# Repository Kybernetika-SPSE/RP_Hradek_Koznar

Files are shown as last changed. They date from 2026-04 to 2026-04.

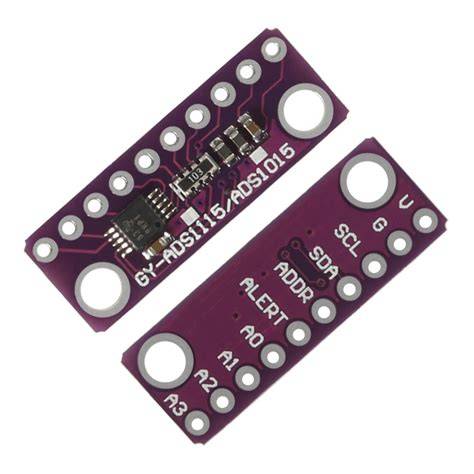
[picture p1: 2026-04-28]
RP_Hradek/reseni/AD_prevodnik/PRILOHA_XII_ads1115.jpg

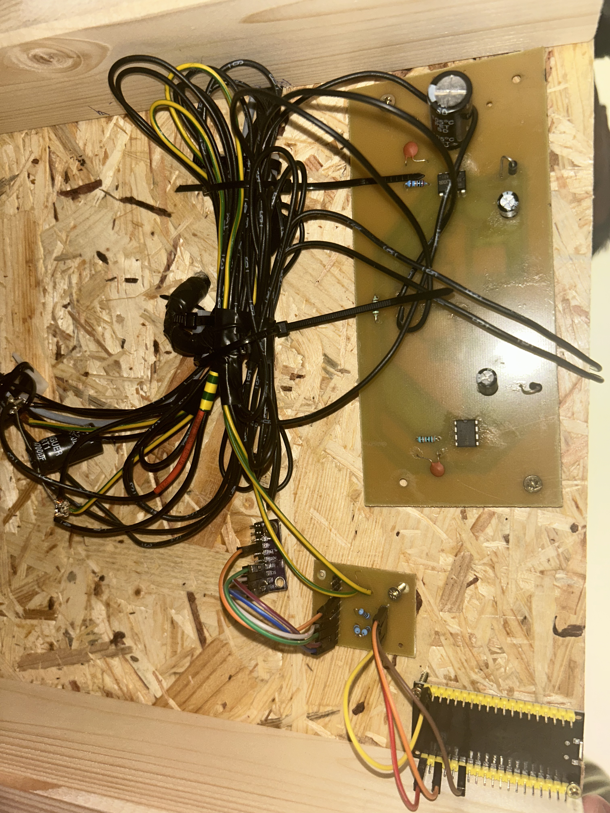
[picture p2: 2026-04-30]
RP_Hradek/reseni/real_fotky/hotovo.jpg

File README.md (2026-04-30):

# KYB Model větrné elektrárny

## Zadání projektu
Model větrné elektrárny

## Řešitelský tým
Štěpán Kožnar, Josef Hrádek

## Vedoucí
Jiří Švihla

## Oponent
Ing. Pavel Jedlička

## Shrnutí projektu
Funkční edukativní model vyrobený z HT potrubí a 3D tištěných PET dílů. Model simuluje přenos energie pomocí systému dvou motorů (motor-generátor) v uzavřené "strojní kleci". Dále zprostředkovává měrění výstupu a popisuje další změny při zpracovávání elektrické energie.

https://discord.gg/VVhzTzu8

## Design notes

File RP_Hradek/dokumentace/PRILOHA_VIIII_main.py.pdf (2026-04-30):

from machine import Pin, I2C
import time

i2c = I2C(0, scl=Pin(22), sda=Pin(21)) addr = 0x48

# kalibrace

gain = 1.00
offset = 0.08

# korekce nad 6V

korekce = 0.98

def read_adc_A0():
config = bytearray(2)
config[0] = 0xC2
config[1] = 0x83

i2c.writeto_mem(addr, 0x01, config) time.sleep(0.1)

data = i2c.readfrom_mem(addr, 0x00, 2)

raw = (data[0] << 8) | data[1]

if raw > 0x7FFF:
raw -= 0x10000

return raw

while True:
raw = read_adc_A0()

# napětí na vstupu ADS1115

v_adc = raw * 0.000125

# základní kalibrace

v_in = (v_adc * 4) * gain - offset

# rozdělení rozsahu

if v_in > 6:
v_in = v_in * korekce

# ochrana

if v_in < 0:
v_in = 0

print(round(v_in, 2))

time.sleep(0.5)

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
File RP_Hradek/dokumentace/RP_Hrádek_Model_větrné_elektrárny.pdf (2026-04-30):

## Vyšší odborná škola

## a Střední průmyslová škola elektrotechnická

## Plzeň, Koterovská 85

## ROCNˇ ÍKOVA PR ´ ACE ´

### Téma:

MODEL VETRN ˇ | E ELEKTR ´ | ARNY ´
Autor práce: | Josef Hrádek
Třída: | 3.L

## Vedoucí práce: Jiří Svihla ˇ

Dne: | 30. 4. 2026

## Hodnocení:

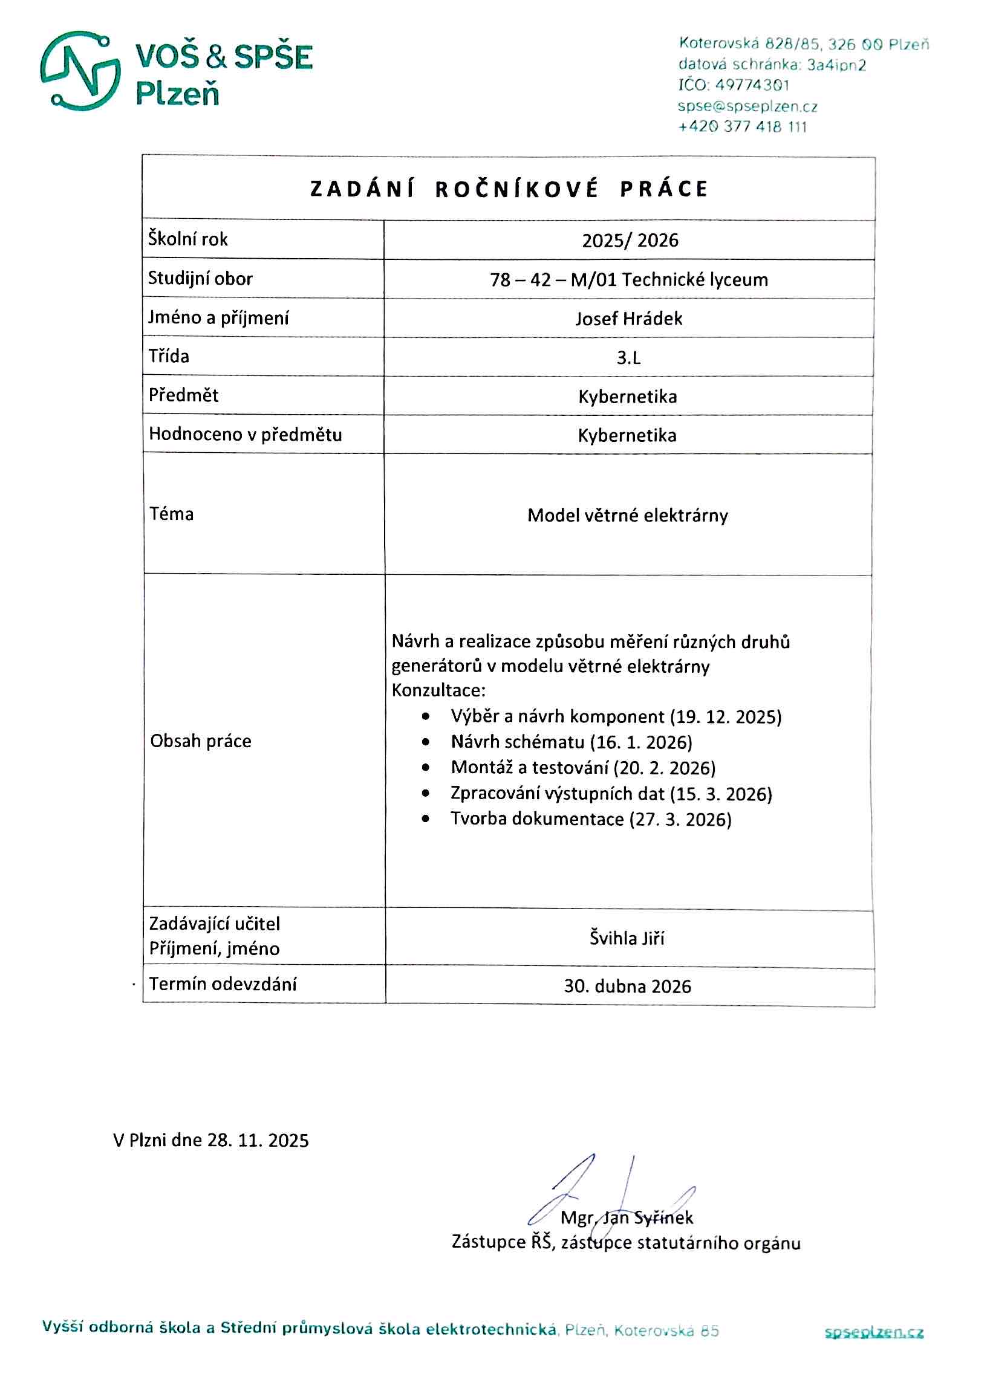
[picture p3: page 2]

## Anotace

Tato ročníková práce se zabývá návrhem a realizací modelu větrné elektrárny. Cílem

práce bylo vytvořit systém umožňující demonstraci přeměny mechanické energie na energii

elektrickou a její následné měření a zpracování.

### Abstrakt

This term project deals with the design and implementation of a model of a wind power

plant. The aim of the project was to create a system that enables the demonstration

of the conversion of mechanical energy into electrical energy, as well as its subsequent

measurement and processing

### Keywords

ADC, energy conversion, ESP32, generator, voltage measurement, wind power plant

Prohlašuji, že jsem tuto práci vypracoval samostatně a použil literárních pramenů a informací,

které cituji a uvádím v seznamu použité literatury a zdrojů informací.

Prohlašuji, že jsem nástroje UI využil v souladu s principy akademické integrity a že na

využití těchto nástrojů v práci vhodným způsobem odkazuji.

Souhlasím s využitím mé práce učiteli VOS a SP ˇ | SE Plzeň k výuce. ˇ
V Plzni dne 30. 4. 2026 | Podpis: |

## Poděkování

Tímto bych rád poděkoval vedoucímu práce Jiřímu Svihlovi za odborné vedení, pomoc ˇ

a připomínky při zpracování této práce. Poděkování patří také mé rodině za podporu

během zpracování této práce.

## Obsah

Seznam zkratek | 7
Uvod ´ | 8
1 Teoretický rozbor | 9
2 Návrh systému | 13

5

3 Praktická realizace | 22
4 Možné varianty řešení | 25
Závěr | 26
Literatura | 27
Přílohy | I

## Seznam zkratek

ADC | Analogově-digitální převodník
AC | Střídavé napětí
DC | Stejnosměrné napětí
ESP32 | Mikrokontrolér

I

2C | Sériová komunikační sběrnice

MOSFET Polem řízený tranzistor

PCB | Deska plošných spojů

7

## Uvod ´

Tato ročníková práce se zabývá návrhem a realizací modelu větrné elektrárny, který slouží

k demonstraci přeměny energie.

Cílem je vytvoření systému, který umožňuje znázornit přeměnu mechanické energie na

energii elektrickou a její následné zpracování. Model zároveň umožňuje měření napětí a

jeho další zpracování pomocí mikrokontroléru a počítače.

V rámci práce je řešen návrh elektrické části systému a měření napětí pomocí analogově-

digitálního převodníku a mikrokontroléru.

Součástí projektu je také popis celkového zapojení, jednotlivých komponent a jejich funkce

v systému.

Projekt byl realizován ve dvoučlenném týmu, přičemž každý člen byl zodpovědný za jinou

část práce. Tato práce se zaměřuje především na elektrickou část, zatímco mechanická

konstrukce modelu byla řešena druhým členem týmu.

Výsledkem práce je model větrné elektrárny s měřicím systémem, který umožňuje sle-

dování napětí a může sloužit jako názorná pomůcka při výuce.

8

## 1 Teoretický rozbor

### 1.1 Princip větrné elektrárny

Větrná elektrárna je zařízení, které přeměňuje kinetickou energii větru na energii elektric-

kou. Základem celého systému je rotor s lopatkami, který je roztáčen větrem.

Tato mechanická energie je následně přenášena na generátor, který ji přeměňuje na energii

elektrickou. Princip této přeměny je založen na elektromagnetické indukci, kdy pohyb

magnetického pole vůči vodiči způsobuje vznik elektrického napětí.

Velikost vyrobené elektrické energie závisí na několika faktorech. Mezi ty hlavní patří rych-

lost větru, velikost rotoru a účinnost jednotlivých částí systému. Se zvyšující se rychlostí

větru roste i výkon elektrárny.

Výkon větrné elektrárny lze přibližně vyjádřit vztahem 1.1:

P =

1
2

ρAv³
(1.1)

kde P je výkon větru, ρ hustota vzduchu, A plocha rotoru a v rychlost větru.

Princip větrné elektrárny je v rámci tohoto projektu využit v modelové podobě, která

umožňuje demonstraci přeměny energie a následné měření napětí.

### 1.2 Typy generátorů

Generátor je zařízení, které přeměňuje mechanickou energii na energii elektrickou. Ve

větrných elektrárnách je generátor poháněn rotorem a představuje tak klíčovou část z

hlediska výroby elektrické energie.

9

Z elektrického hlediska lze generátory rozdělit na stejnosměrné a střídavé podle charakteru

výstupního napětí.

### 1.2.1 Stejnosměrné generátory

Stejnosměrný generátor vytváří na výstupu napětí s konstantní polaritou. V jednodušších

aplikacích může být jako generátor použit například stejnosměrný motor provozovaný v

režimu generátoru, označovaný jako dynamo.

Výhodou tohoto řešení je především jednoduchost zapojení a snadné měření výstupního

napětí, protože není nutné dále upravovat signál před jeho zpracováním.

Základní vztah mezi elektrickými veličinami lze vyjádřit vztahem 1.2:

P = U · I | (1.2)

kde P je elektrický výkon, U napětí a I proud.

### 1.2.2 Střídavé generátory

Na rozdíl od stejnosměrných generátorů, střídavý generátor produkuje napětí, které se v

čase mění. Tento typ generátoru je běžný zejména u větších elektráren, kde je výhodný

pro přenos elektrické energie.

Pro další zpracování je však často nutné toto napětí upravit, například pomocí usměrňovače

nebo filtračních obvodů. Měření střídavého napětí je obecně složitější než u stejnosměrného

napětí, protože je nutné zohlednit jeho časový průběh nebo efektivní hodnotu.

Při výpočtu výkonu ve střídavých obvodech je nutné uvažovat také účiník, který vyjadřuje

fázový posun mezi napětím a proudem. Výkon lze pak vyjádřit vztahem 1.3:

10

P = U · I · cos φ | (1.3)

kde U je efektivní hodnota napětí, I efektivní hodnota proudu a cos φ účiník. Učiník ´

vyjadřuje poměr mezi skutečně využitým výkonem a celkovým zdánlivým výkonem ve střídavém obvodu. Učiník může nabývat hodnot mezi 0 a 1. Vyjadřuje fázový posun mezi ´

napětím a proudem.

V rámci tohoto projektu je proto využit stejnosměrný generátor, který umožňuje jed-

nodušší měření a zpracování získaných dat.

### 1.3 Přeměny elektrické energie

V elektrických systémech je často nutné upravovat vlastnosti elektrické energie podle

různých požadavků. Mezi základní úpravy patří změna typu napětí, jeho velikosti nebo

jeho časového průběhu.

Jednou ze základních přeměn je usměrnění, tedy převod střídavého napětí na napětí stej-

nosměrné. K tomu se používají usměrňovače, které jsou tvořeny nejčastěji polovodičovými

diodami a vyhlazovacím kondenzátorem.

Další důležitou přeměnou je převod stejnosměrného napětí na střídavé. Tento proces zajišt’ují střídače, které vytvářejí střídavé napětí z napětí stejnosměrného. Střídače se

využívají například u zařízení vyžadujících střídavé napětí nebo při připojení zdrojů ener-

gie k elektrické síti.

Pro změnu velikosti střídavého napětí se používají transformátory. Ty umožňují zvyšovat

nebo snižovat napětí podle potřeby. Proud je přitom nepřímo úměrný k napětí. Základní

vztah transformátoru lze vyjádřit vztahem 1.4:

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
(1.4)

kde U1 a U2 jsou napětí na primární a sekundární straně, I1 a I2 proudy na primární a

11 sekundární straně a N1, N2 počty závitů vinutí.

Učinnost přeměny lze vyjádřit jako poměr výstupního a vstupního výkonu podle vztahu 1.5: ´

η =

Pout

Pin

(1.5)

kde η je účinnost, Pout výstupní výkon a Pin vstupní výkon.

Každá z těchto přeměn je však spojena s energetickými ztrátami, které vznikají například

na polovodičových prvcích nebo vinutí transformátorů. Tyto ztráty se projevují snížením

účinnosti celého systému.

12

## 2 Návrh systému

Kapitola návrh systému se zaměřuje na návrh modelu větrné elektrárny z hlediska jeho

elektrické části. Zde jsem popsal jednotlivé bloky systému, jejich funkce a vzájemné pro-

pojení.

Veškeré obvody a PCB jsou navrženy v programu KiCad.

### 2.1 Blokové schéma systému

Navržený model větrné elektrárny mohu přehledně popsat pomocí blokového schématu,

které znázorňuje jednotlivé části systému a jejich vzájemné propojení. Blokové schéma

slouží jako základní orientační prvek pro pochopení funkce celého zařízení.

Na obrázku 2.1 je zobrazeno rozdělení systému do několika hlavních bloků. Prvním z nich

je generátor. Na generátor navazuje měřicí část, která umožňuje sledování napětí.

Další částí je zpracování elektrické energie vedené do energetické části, kde může docházet

k její další úpravě, například převodu na střídavé napětí a transformaci.

V blokovém schématu je vidět, že části systému jsou navrženy modulárně, takže je možné

abych je jednoduše a samostatně testoval.

13

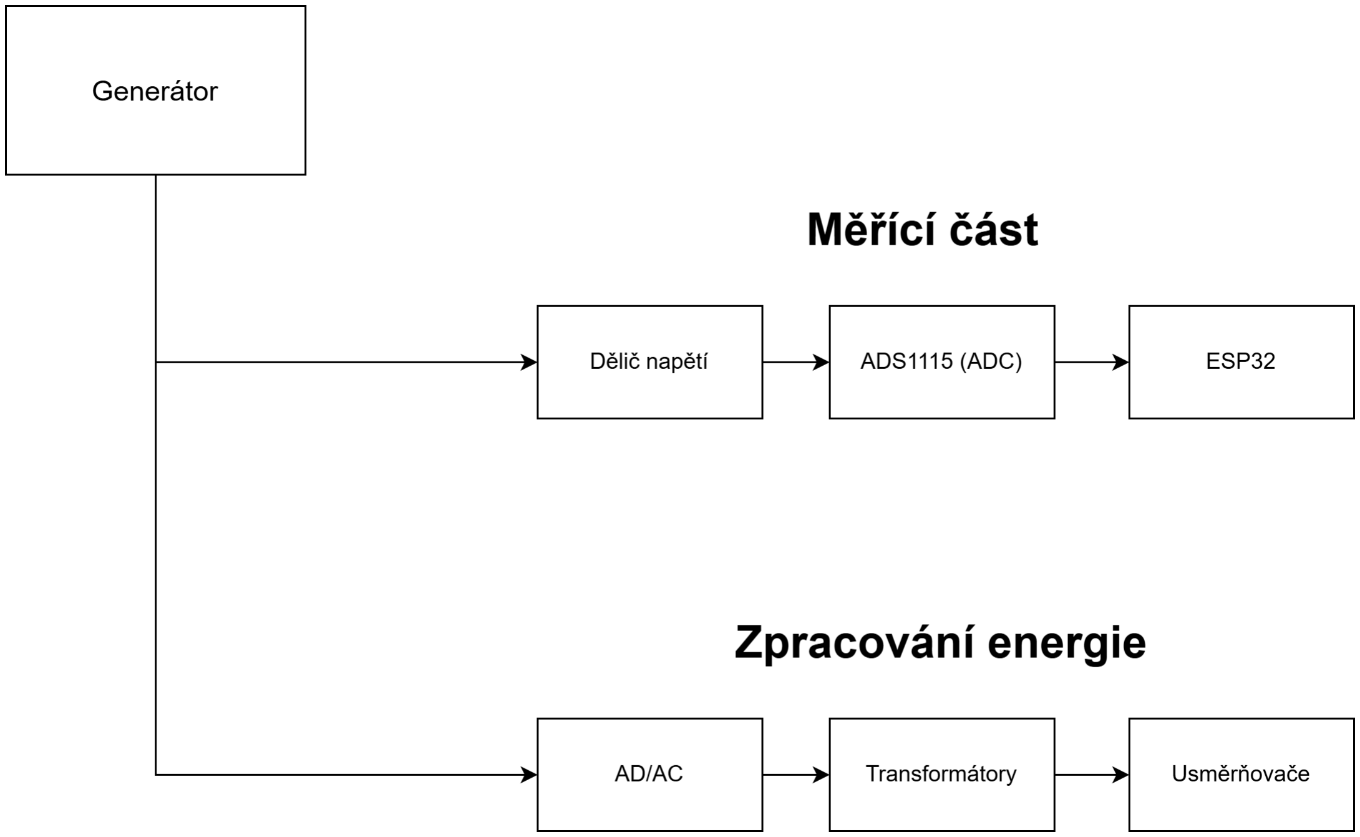
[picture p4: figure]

Obrázek 2.1: Blokové schéma systému

### 2.2 Generátor

Jako zdroj elektrické energie jsem použil stejnosměrný motor pracující v režimu ge-

nerátoru. Tento motor převádí mechanickou energii na energii elektrickou na základě

principu elektromagnetické indukce.

Konkrétně byl v modelu použit stejnosměrný motor QSX-545[1] s napětím 12 V. Tento

motor patří mezi běžné kartáčové DC motory s permanentními magnety, díky čemuž ho

lze využít jako motor, ale i jako generátor.

Motor dosahuje při napětí 12 V přibližně 7000 ot/min a jeho výkon je přibližně 30 W.

Tyto parametry jsou pro daný model dostatečné a umožňují generovat napětí vhodné pro

další měření a zpracování.

V našem modelu je generátor poháněn jiným elektromotorem, který zajišt’uje jeho otáčení.

Simuluje tím funkci větrné turbíny, která by v reálném případě byla poháněna prouděním

vzduchu.

14

Použití stejnosměrného motoru jako generátoru je výhodné zejména kvůli jednoduchosti

zapojení a snadnému měření výstupního napětí.

### 2.3 Měřicí část

Měřicí část slouží k získávání a zpracování napětí generovaného v modelu větrné elektrárny.

Cílem této části je měření napětí generátoru a jeho následné digitální zpracování.

Napětí generátoru nelze přivést přímo na vstup AD převodníku, protože by mohlo dojít

k překročení maximálního povoleného vstupního napětí a převodník zničit. Kvůli tomu je

v systému použit dělič napětí, který snižuje měřené napětí na bezpečnou úroveň.

Takto upravené napětí je následně přivedeno na AD převodník [2], který jej převádí na di-

gitální hodnotu. Tyto hodnoty jsou dále zpracovávány mikrokontrolérem ESP32[3], který zajišt’uje jejich vyhodnocení a přenos do počítače.

K programování jsem použil vývojové prostředí Visual Studio Code.

### 2.3.1 Dělič napětí

Dělič napětí je jednoduchý obvod složený ze dvou rezistorů, který slouží ke snížení měřeného

napětí na hodnotu vhodnou pro další zpracování.

Dělič napětí je založen na rozdělení vstupního napětí mezi dva rezistory. Výstupní napětí

je odebíráno z uzlu mezi těmito rezistory. Hodnota výstupního napětí závisí na poměru

odporů použitých rezistorů.

Výstupní napětí děliče lze vyjádřit vztahem:

Uout = Uin ·

R2
R1 + R2

(2.1)

kde Uin je vstupní napětí, Uout výstupní napětí děliče a R1, R2 jsou odpory jednotlivých

15

rezistorů.

V tomto projektu byly zvoleny hodnoty rezistorů R1 = 3000 Ω a R2 = 1000 Ω. Po dosazení

do vztahu 2.1 lze určit poměr dělení:

Uout = Uin ·

1000
3000 + 1000

= Uin ·

1
4

(2.2)

Z toho vyplývá, že výstupní napětí děliče je přibližně čtvrtinové oproti vstupnímu napětí.

A jelikož generátor dodává maximálně 12 V, je naprosto bezpečné toto napětí přivádět

na AD převodník i ESP32 s tolerancí 3,3 V.

### 2.3.2 Analogově-digitální převodník

ADC slouží k převodu analogového napětí na digitální hodnotu, kterou je možné dále zpra-

covávat mikrokontrolérem. V tomto projektu je použit externí převodník typu ADS1115.

ADS1115 umožňuje měření napětí s vysokým rozlišením 16 bitů, takže dokáže převést

vstupní napětí na 65536 hodnot. Díky tomu je možné dosáhnout přesnějšího měření než

při použití vestavěného ADC mikrokontroléru.

Další výhodou tohoto převodníku je možnost komunikace pomocí sběrnice I²C, což umožňuje

snadné propojení s mikrokontrolérem ESP32.

Napětí z děliče je přivedeno na vstup převodníku, kde je převedeno na digitální hodnotu.

Tato hodnota je následně odeslána do mikrokontroléru, který ji dále zpracovává.

### 2.3.3 Mikrokontrolér ESP32

ESP32 je výkonná řídicí jednotka. Obsahuje dvoujádrový procesor, integrovanou pamět’

a řadu komunikačních rozhraní, jako je například I²C, SPI nebo UART.

Výhodou tohoto mikrokontroléru je také integrovaná podpora bezdrátové komunikace

16


Obrázek 2.2: Použitý analogově-digitální převodník ADS1115

pomocí Wi-Fi a Bluetooth. Díky tomu je možné jej využít v široké škále aplikací, od

jednoduchých měřicích systémů až po složitější projekty.

ESP32 lze programovat v různých programovacích jazycích, přičemž v tomto projektu je

využit jazyk MicroPython, který umožňuje rychlý a přehledný vývoj.

### Použití mikrokontroléru v projektu

V tomto projektu je mikrokontrolér ESP32 využit jako hlavní řídicí jednotka měřicího systému. Zajišt’uje komunikaci s analogově-digitálním převodníkem ADS1115 a získává z

něj digitální hodnoty odpovídající měřenému napětí.

Naměřená data jsou mikrokontrolérem dále zpracována a následně odesílána do počítače,

kde dochází k jejich dalšímu vyhodnocení.

ESP 32 tak plní klíčovou roli v celém systému, protože propojuje jednotlivé části měřicího řetězce a zajišt’uje správnou funkci celého zařízení.

17

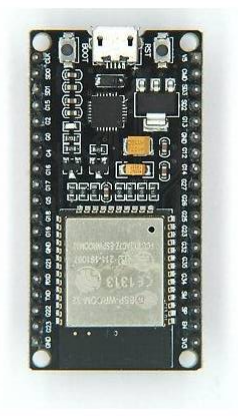
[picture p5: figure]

Obrázek 2.3: Použitý mikrokontrolér ESP32

18

### 2.4 Zpracování dat

Po převodu analogového napětí na digitální hodnotu pomocí AD převodníku dochází k

jeho dalšímu zpracování mikrokontrolérem. Digitální data odpovídají konkrétním hod-

notám napětí.

Mikrokontrolér provádí základní zpracování dat a jejich přípravu pro další přenos. Naměřené

hodnoty jsou následně odesílány do osobního počítače, kde dochází k jejich dalšímu vy-

hodnocení.

### 2.5 Energetická část

Tato část systému je o dalším zpracováním elektrické energie generované modelem větrné

elektrárny. V této části dochází k přeměně napětí a jeho úpravě tak, aby bylo možné

demonstrovat různé typy elektrické energie.

Celá energetická část zahrnuje DC/AC střídač, transformátor a usměrňovač, jenž umožňují

změny napětí.

### 2.5.1 Střídač

Tento důležitý komponent slouží k převodu stejnosměrného napětí na střídavé napětí. V tomto projektu jsem použil zapojení založené na integrovaném obvodu IR2153[4] a

výkonových tranzistorech IRF3205[5].

Jeho činnost spočívá v periodickém spínání tranzistorů, čímž dochází ke změně polarity

napětí na výstupu. Tím vzniká střídavé napětí, které je následně přivedeno na trans-

formátor.

Integrovaný obvod IR2153 zajišt’uje generování řídicích signálů pro tranzistory, čímž

umožňuje vytvoření jednoduchého DC/AC střídače bez nutnosti složitého řízení.

19

Střídač tak představuje klíčovou část, která umožňuje převod energie z generátoru do

formy střídavého napětí.

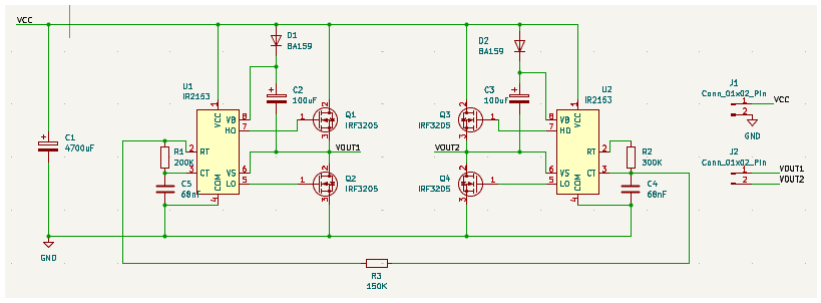
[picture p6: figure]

Obrázek 2.4: Schéma zapojení střídače vytvořené v programu KiCad[7]

### 2.5.2 Transformátor

Transformátor je součástka, která slouží ke změně velikosti střídavého napětí. V tomto projektu jsem použil transformátor 12/230 V, který umožňuje zvýšení napětí na vyšší

hodnotu.

Transformátor funguje na bázi elektromagnetické indukce, kdy se energie přenáší mezi

primárním a sekundárním vinutím pomocí magnetického pole.

Použití transformátoru umožňuje přizpůsobení výstupního napětí požadovaným hodnotám a zároveň zajišt’uje galvanické oddělení jednotlivých částí systému.

### 2.5.3 Usměrňovač

Usměrňovač slouží k převodu střídavého napětí zpět na napětí stejnosměrné. V tomto

projektu jsem ho realizoval pomocí diod typu BA159.

Princip usměrnění spočívá v tom, že diody propouštějí proud pouze jedním směrem, čímž

20 dochází k odstranění záporné části střídavého signálu.

Výstupem usměrňovače je pulzující stejnosměrné napětí, které může být dále upraveno

například pomocí vyhlazovacího kondenzátoru.

Zařazení usměrňovače do systému umožňuje demonstraci kompletního cyklu přeměny elek-

trické energie mezi stejnosměrnou a střídavou formou.

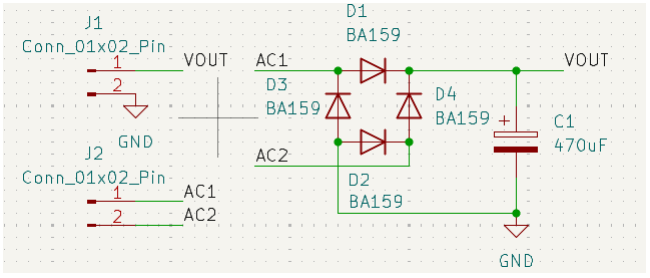
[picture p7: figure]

Obrázek 2.5: Schéma zapojení usměrňovače vytvořené v programu KiCad

21

## 3 Praktická realizace

### 3.1 Měřicí část a ověření systému

Měřicí část jsem sestavil na základě návrhu uvedeného v předchozí kapitole.

Základem měřicí části je dělič napětí, který slouží ke snížení napětí generátoru na hod-

notu vhodnou pro analogově-digitální převodník. Dělič jsem realizoval pomocí rezistorů s

hodnotami R1 = 3000 Ω a R2 = 1000 Ω.

Takto upravené napětí jsem přivedl na analogově-digitální převodník ADS1115, který

převádí analogový signál na digitální hodnotu. Převodník je propojen s mikrokontrolérem ESP32 pomocí sběrnice I²C.

Mikrokontrolér zajišt’uje zpracování naměřených dat a jejich odesílání do počítače. Celý

systém jsem testoval pomocí stejnosměrného zdroje napětí, který simuloval výstup ge-

nerátoru.

Při testování jsem nejprve ověřil správnou hodnotu napětí přes multimetr a komunikaci

mezi jednotlivými částmi systému. Poté jsem změřil napětí pomocí měřícího systému 3.1.

Naměřené hodnoty odpovídaly očekávaným výsledkům s ohledem na použitý dělič napětí.

22

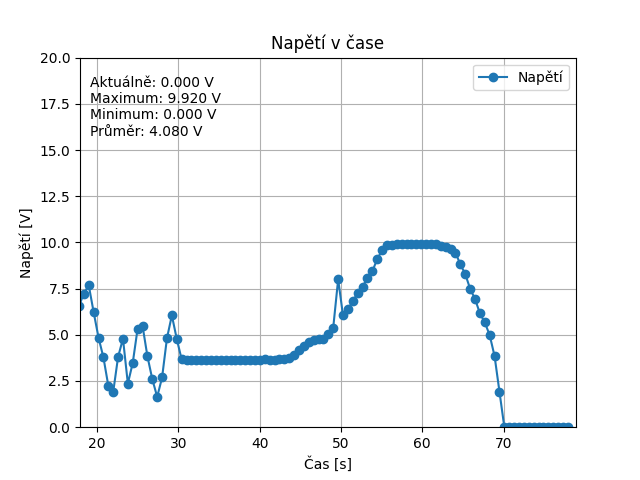
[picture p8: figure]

Obrázek 3.1: Graf výstupního napětí generátoru v čase

### 3.2 Generátor

Při praktickém testování jsem ověřil, že generátor vytváří napětí závislé na rychlosti

otáčení. Se zvyšující se rychlostí otáčení dochází ke zvýšení výstupního napětí, což od-

povídá teoretickým předpokladům.

Generátor je mechanicky propojen s modelem větrné elektrárny. A elektricky propojen se

zbytkem soustavy.

### 3.3 Celkový systém

Při kompletaci a testování energetické části systému se vyskytly problémy s funkcí střídače.

Nepodařilo se, i přes několik pokusů a výměně nekterých součástek, dosáhnout výstupního

napětí, a proto není tato část systému plně funkční.

23

Proto není možné využít transformátorů a usměrňovače pro ukázku přeměny napětí.

Na obrázcích 3.2 a 3.3 jsou vidět desky pro plošné spoje a realizace zapojení na spodní

straně podložky pro model.

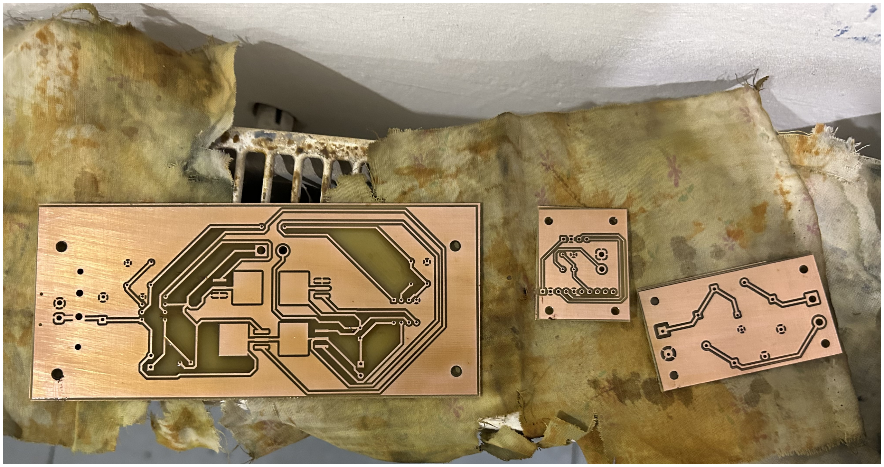
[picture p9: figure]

Obrázek 3.2: ve škole vytvořené plošné spoje

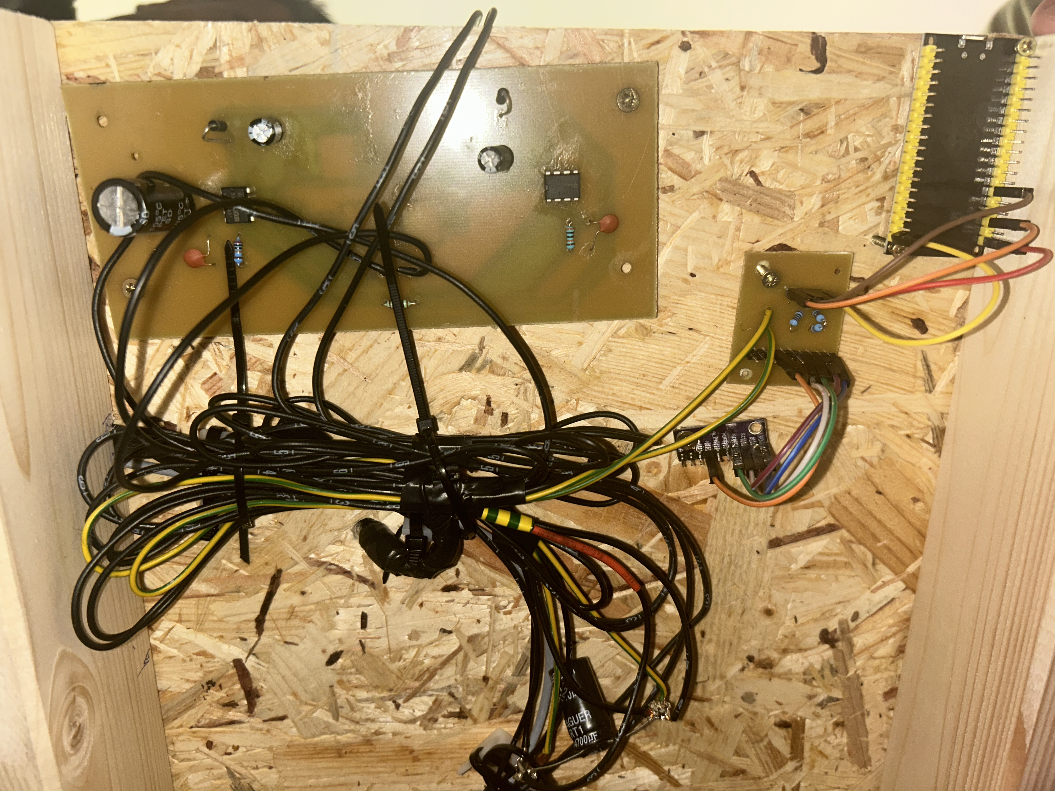
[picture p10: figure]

Obrázek 3.3: realizace zapojení

24

## 4 Možné varianty řešení

V rámci projektu jsem zvolil stejnosměrný generátor realizovaný pomocí DC motoru. Toto

řešení jsem vybral především pro svou jednoduchost, dostupnost a snadnou implementaci.

Výhodou je také jednoduché měření výstupního napětí, které není nutné dále upravovat.

Alternativní možností by bylo použití střídavého generátoru. Tento typ generátoru je

běžně využíván ve skutečných větrných elektrárnách. Nevýhodou tohoto řešení je však

jeho větší rozměr a složitější konstrukce. Střídavé generátory často vyžadují buzení, což

znamená nutnost dodatečného napájení budicího vinutí.

Další variantou by bylo použití jiného typu analogově-digitálního převodníku nebo mi-

krokontroléru. Zvolený převodník ADS1115 a mikrokontrolér ESP32 však poskytují do-

statečný výkon a přesnost pro účely tohoto projektu.

Z hlediska energetické části by bylo možné systém dále rozšířit například o stabilizaci

napětí nebo efektivnější typ střídače.

25

## Závěr

Cílem práce bylo navrhnout a realizovat model větrné elektrárny s důrazem na měření a

zpracování elektrického napětí.

V rámci práce byl navržen systém skládající se z generátoru, měřicí části a energetické

části. Bylo vytvořeno blokové schéma a popsány jednotlivé komponenty systému.

Měřicí část byla realizována pomocí děliče napětí, analogově-digitálního převodníku a

mikrokontroléru ESP32. Byla ověřena její funkčnost a schopnost měřit napětí a předávat

data k dalšímu zpracování.

Součástí návrhu byla také energetická část, která umožňuje přeměnu elektrické energie pomocí transformátoru, usměrňovače a DC/AC střídače, u kterého se při testování vyskytly

problémy a není funkční.

### Práce v týmu

Projekt byl realizován ve dvoučlenném týmu, přičemž jednotlivé části práce byly mezi

členy rozděleny.

Já jsem se v této práci zaměřil především na návrh a realizaci elektrické části systému,

zejména měřicí části, zpracování dat a energetické části. Kolega byl zodpovědný za me-

chanickou konstrukci modelu větrné elektrárny.

Během práce mezi námi probíhala spolupráce, zejména při návrhu celkového systému a

jeho finálním propojení. Díky rozdělení práce bylo možné efektivně řešit jednotlivé části

projektu.

26

## Literatura

[1] TECHFUN. DC motor QSX-545 12 V. [online]. Dostupné z: https://techfun.cz/

produkt/motorek-12v-qsx-545/ (https://techfun.cz/produkt/motorek-12v-qsx-545/)

[2] TEXAS INSTRUMENTS. ADS1115 – 16-Bit Analog-to-Digital Converter. [online].

Dostupné z: https://www.ti.com

[3] ESPRESSIF SYSTEMS. ESP32 Technical Reference Manual. [online]. Dostupné

z:https://docs.espressif.com/projects/esp-dev-kits/en/latest/esp32/

esp32-devkitc/user_guide.html (https://docs.espressif.com/projects/esp-dev-kits/en/latest/esp32/esp32-devkitc/user_guide.html)

[4] INFINEON TECHNOLOGIES. IR2153 – Self-Oscillating Half-Bridge Driver. [on-

line]. Dostupné z: https://www.infineon.com/part/IR2153

[5] INFINEON TECHNOLOGIES. IRF3205 – Power MOSFET. [online]. Dostupné z:

https://www.infineon.com/part/IRF3205S

[6] DIOTEC SEMICONDUCTOR. BA159 – Rectifier Diode. [online]. Dostupné z:

https://diotec.com/en/product/BA159.html

[7] DANYK. Měnič 230 V. [online]. Dostupné z: https://danyk.cz/menic230_5.html
[8] KICAD. KiCad EDA. [online]. Dostupné z: https://www.kicad.org
[9] MICROSOFT. Visual Studio Code. [online]. Dostupné z: https://code.

visualstudio.com (https://code.visualstudio.com)

[10] PYTHON SOFTWARE FOUNDATION. Python Programming Language. [online].

Dostupné z: https://www.python.org

[11] MICROPYTHON. MicroPython for ESP32. [online]. Dostupné z: https://

micropython.org/download/esp32

27

[12] SILICON | LABORATORIES. | CP210x | USB | to | UART | Bridge | VCP
Drivers. | [online]. | Dostupné | z: | https://www.silabs.com/developers/

usb-to-uart-bridge-vcp-drivers (https://www.silabs.com/developers/usb-to-uart-bridge-vcp-drivers)

[13] WIKIPEDIA. Větrná elektrárna. [online]. Dostupné z: https://cs.wikipedia.org/

wiki/V%C4%9Btrn%C3%A1_elektr%C3%A1rna (https://cs.wikipedia.org/wiki/V%C4%9Btrn%C3%A1_elektr%C3%A1rna)

[14] NAZORN ´ | A ELEKTROTECHNIKA. ´ | YouTube kanál – Názorná elektrotechnika. [on-

line]. Dostupné z: https://www.youtube.com/@nazornaelektrotechnika

[15] OPENAI. ChatGPT. [online]. Dostupné z: https://chatgpt.com

28

## Přílohy

### Obvody

Příloha I: usmernovac.kicad sch

Příloha II: H-mustek.kicad sch

Příloha III: AD prevodnik.kicad sch

Příloha IV: usmernovac.kicad pcb

Příloha V: H-mustek.kicad pcb

Příloha VI: AD prevodnik.kicad pcb

### Programy

Příloha VII: graf.py

Příloha VIII: main.py

Příloha IX: graf napeti.png

### Ostatní přílohy

Příloha X: esp32.png

Příloha XI: blokove schema.png

Příloha XII: ads1115.jpg

I

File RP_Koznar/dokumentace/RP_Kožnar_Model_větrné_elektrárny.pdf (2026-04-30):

## Vyšší odborná škola

## a Střední průmyslová škola elektrotechnická

## Plzeň, Koterovská 85

## ROČNÍKOVÁ PRÁCE

Téma:

## Model větrné elektrárny

Autor práce: | Štěpán Kožnar
Třída: | 3.L
Vedoucí práce: | Jiří Švihla
Dne: | 30.4.2026

## Hodnocení:

### Z A D Á N Í R O Č N Í K O V É P R Á C E

Školní rok | 2025/ 2026
Studijní obor | 78 – 42 – M/01 Technické lyceum
Jméno a příjmení | Štěpán Kožnar
Třída | 3.L
Předmět | Kybernetika
Hodnoceno v předmětu | Kybernetika
Téma | Model větrné elektrárny
Obsah práce | Návrh nosné konstrukce větrné elektrárny a její sestavení Konzultace: • Návrh nosné konstrukce elektrárny (19. 12. 2025) • Optimalizace konstrukce – návrh uchycení komponent (30. 1. 2026) • Zapracování komponent, prvků do modelu (20. 2. 2026) • Sestavení (13. 3. 2026) • Tvorba dokumentace (27. 3. 2026)
Zadávající učitel Příjmení, jméno | Švihla Jiří
Termín odevzdání | 30. dubna 2026

V Plzni dne 28. 11. 2025

Mgr. Jan Syřínek
Zástupce ŘŠ, zástupce statutárního orgánu

## Anotace

Tato ročníková práce se zabývá návrhem a realizací edukativního modelu větrné elektrárny s využitím moderních metod aditivní výroby a dostupných konstrukčních prvků. Hlavním cílem práce bylo navrhnout nosnou konstrukci z HT trubek a vytvořit zakázkové 3D komponenty zajišťující přesné uložení pohonných jednotek.

Praktická část práce popisuje proces ladění tolerancí 3D tištěných dílů a realizaci unikátního systému dvou motorů pro demonstraci přenosu a generování elektrické energie. Výsledkem je funkční učební pomůcka, která názorně ilustruje fyzikální principy větrné energetiky.

### Klíčová slova

Větrná elektrárna, 3D tisk, HT potrubí, aditivní výroba, Autodesk Inventor, edukativní model, stejnosměrný motor, přenos energie.

### Abstract

This term project focuses on the design and realization of an educational wind turbine model, utilizing modern additive manufacturing methods and accessible structural components. The primary objective was to design a support structure made of HT piping and to create custom 3D-printed components ensuring the precise mounting of the drive units.

The practical part of the project describes the process of fine-tuning tolerances for 3D-printed parts and the implementation of a unique dual-motor system for demonstrating the transfer and generation of electrical energy. The result is a functional educational tool that clearly illustrates the physical principles of wind power engineering.

### Key words

Wind turbine, 3D printing, HT piping, additive manufacturing, Autodesk Inventor, educational model, DC motor, energy transfer.

4

## Poděkování

Rád bych poděkoval vedoucímu ročníkové práce panu Jiřímu Švihlovi za odborné vedení,

cenné rady a čas, který mi věnoval při konzultacích.

Dále děkuji paní učitelce Ing. Lence Kralové, Ing. Šárce Blechové Ph.D. a panu učiteli Ing.

Pavlu Jedličkovi za jejich pomoc při řešení technických problémů spojených s konstrukcí modelu a praktickou realizací projektu.

Prohlašuji, že jsem tuto práci vypracoval samostatně a použil literárních pramenů a informací, které cituji a uvádím v seznamu použité literatury a zdrojů informací.

Prohlašuji, že jsem nástroje UI využil v souladu s principy akademické integrity a že na využití těchto nástrojů v práci vhodným způsobem odkazuji.

Souhlasím s využitím své práce učiteli VOŠ a SPŠE Plzeň k výuce.

V Plzni dne 30. 4. 2026 | Podpis: |

## Obsah

Seznam obrázků | 8
Seznam tabulek | 9
Seznam použitých symbolů a zkratek | 10
Úvod | 11
1 Teoretická část | 12
2 Návrh a volba materiálů | 15
3 Technická realizace | 20

4 Princip funkčnosti a ověření | 25
Závěr | 29
Seznam použité literatury a zdrojů | 31
Přílohy | I

## Seznam obrázků

2.1 Prostředí autodesk inventor | 16
2.2 Zdroj Dell | 18
2.3 Sestava motorů | 18
3.1 Lůžko pro motor QSX 545 | 21
3.2 Lůžko pro motor RF12-002 | 22
4.1 Upravený zdroj s regulátory | 26
4.2 Multimetr - Uout | 27
4.3 Model větrné elektrárny | 30

8

## Seznam tabulek

2.1 Technické specifikace hlavních motorů soustrojí | 17
2.2 Technické specifikace hlavních motorů soustrojí | 17

9

## Seznam použitých zkratek a symbolů

Zkratka / Symbol Význam | Jednotka
HAWT | Horizontal Axis Wind Turbine (turbína s horizontální
| osou) | -
VAWT | Vertical Axis Wind Turbine (turbína s vertikální osou) -
HT | Hochtemperatur (vysokoteplotní polypropylenové po-
| trubí) | -
PET | Polyethylentereftalát (materiál lůžek pro 3D tisk) | -
PSU | Power Supply Unit (napájecí zdroj Dell) | -
DC | Direct Current (stejnosměrný proud) | -
RPM | Revolutions Per Minute (otáčky za minutu) | min⁻¹
D-shaft | Hřídel ve tvaru písmene D (zajištění proti prokluzu) | -
VE | Větrná elektrárna | -
Uin | Vstupní napětí na hnacím motoru | V
Uout | Výstupní napětí na generátoru | V
I | Elektrický proud | A
P | Výkon | W
R | Elektrický odpor vinutí motoru | Ω
ηu | Napěťová účinnost systému | %
v | Rychlost proudění vzduchu | m/s
ρ | Hustota vzduchu | kg · m⁻³
A | Plocha opsaná rotorem | m²

10

## Úvod

V dnešní době se o obnovitelných zdrojích mluví stále častěji, ale pro mnoho lidí je princip větrné elektrárny stále tak trochu „černá skříňka“. Jako student technického lycea jsem chtěl vytvořit něco, co proces výroby elektřiny z větru ukáže v praxi a srozumitelně.

Cílem mé ročníkové práce je návrh a stavba funkčního modelu větrné elektrárny, který bude sloužit jako edukativní pomůcka. Nechtěl jsem stavět jen statickou maketu, ale zařízení, na kterém se dají reálně měřit hodnoty a demonstrovat pohyb. Při konstrukci jsem se zaměřil na tři hlavní oblasti:

Využití moderních i dostupných materiálů: Nosnou konstrukci tvoří klasické HT trubky, které jsou lehké a snadno opracovatelné. Aby vše drželo pohromadě a komponenty přesně lícovaly, navrhl jsem si vlastní spojky a úchyty pro 3D tisk.

Třímotorový systém pro simulaci a výrobu: Model využívá celkem tři motory. První motor zajišťuje rotaci samotného rotoru pro vizuální efekt. Další dva motory jsou umístěny v zadní části a jsou mechanicky propojeny: jeden slouží jako pohon hřídele a druhý jako generátor. Tato sestava umožňuje demonstrovat přeměnu energie i v uzavřených prostorách bez nutnosti silného větru.

Modularita a rozebíratelnost: Celý model je vymyšlený tak, aby se dal snadno složit a rozložit, což je ideální jednak pro transport, jednak pro názornou ukázku toho, jak jsou jednotlivé součástky uvnitř trubek propojeny.

V této práci popíšu celý postup – od kreslení dílů v Autodesk Inventor přes řešení tolerancí u 3D tisku až po finální měření, kolik elektřiny je tento systém schopen vyrobit a s jakou účinností.

11

## 1 Teoretická část

Před popisem samotné konstrukce a měření je nutné si ujasnit fyzikální principy, na kterých větrné elektrárny fungují. Tato kapitola tedy popisuje, jak se energie větru transformuje na elektřinu, jaké konstrukční koncepce se v praxi používají a proč jsem pro svůj projekt zvolil právě systém s horizontální osou. Pochopení teorie mi v dalších fázích projektu pomohlo správně nadimenzovat rotor a navrhnout měřicí okruh pro zjišťování účinnosti.

### 1.1 Princip větrné energie

Základním principem větrné energie je přeměna kinetické energie (Ek) proudícího vzduchu na energii mechanickou a následně na energii elektrickou. Tento proces probíhá prostřednictvím rotoru větrné turbíny, který je navržen tak, aby zachytil sílu větru a převedl ji na točivý moment hřídele.

Klíčovou roli zde hraje aerodynamika listů rotoru. Narozdíl od historických větrných mlýnů, které využívaly především odpor vzduchu, moderní větrné elektrárny pracují na principu aerodynamického vztlaku. Ten vzniká díky speciálnímu profilu lopatky, podobně jako u křídel letadla.

P =

1
2

ρAv³

Ve vzorci pro výkon větru můžeme vidět, že výkon roste se třetí mocninou rychlosti větru (v

3
), tudíž při dvojnásobné rychlosti větru bude energie/výkon osmkrát větší.

12

### 1.2 Typy větrných elektráren

Větrné elektrárny se v základu dělí podle orientace osy otáčení rotoru na dvě hlavní skupiny: turbíny s horizontální osou (HAWT – Horizontal Axis Wind Turbine) a turbíny s vertikální osou (VAWT – Vertical Axis Wind Turbine).

V současné průmyslové energetice jednoznačně dominují elektrárny s horizontální osou (HAWT), což je koncepce využitá i v tomto projektu. Jejich hlavní výhodou je vyšší účinnost a možnost instalace ve velkých výškách, kde je proudění vzduchu stabilnější. Na druhou stranu však vyžadují mechanismus pro natáčení proti směru větru. Díky své konstrukci umožňují plynulou regulaci výkonu pomocí natáčení jednotlivých listů rotoru (tzv. pitch regulace), což je zásadní pro ochranu turbíny při extrémně silném větru.

Využívají se ale i elektrárny s vertikální osou (VAWT), především v městské zástavbě. Existují dva typy:

Darrieův rotor využívá vztlakové síly větru (podobně jako křídla u letadel). Má vysokou účinnost a vysoké otáčky, ale většinou se sám nedokáže roztočit z klidu. Je vhodný pro výrobu elektřiny.

Savoniův rotor pracuje na principu rozdílného odporu vzduchu u lžícovitě tvarovaných lopatek. Jeho hlavní výhodou je schopnost reagovat na vítr z jakéhokoliv směru a vysoký krouticí moment už při slabém větru. Nevýhodou je však výrazně nižší účinnost ve srovnání s ostatními typy.

### 1.3 Konstrukční prvky

Aby mohla větrná elektrárna správně fungovat, musí být sestavena z několika klíčových součástí. U průmyslových elektráren je základem nosný tubus (věž), který drží gondolu v dostatečné výšce, kde je proudění větru nejsilnější, a tudíž nejlepší pro výrobu elektrické energie.

Gondolu můžeme označit za srdce nebo strojovnu celé větrné elektrárny. Jedná se o

13 bezpečný kryt, který je umístěn na vrcholu VE a který chrání umístěné komponenty, mezi něž patří generátor, hřídele, ložiska, převodovka a veškerá elektronika, před vnějšími povětrnostními vlivy, a to deštěm, prachem a silným větrem. U skutečných elektráren bývá gondola otočná, aby se rotor mohl vždy nastavit přímo proti směru větru. V mém projektu je funkce gondoly realizována pomocí HT T-kusu, který slouží jako hlavní propojovací uzel celého modelu.

Dalším důležitým prvkem je rotor, jenž tvoří náboj a listy (lopatky). U moderních strojů se listy vyrábějí z kompozitních materiálů, a to z důvodu jejich lehkosti a pevnosti. V mém projektu jsem tyto složité průmyslové díly nahradil dostupnějšími materiály. Místo ocelové věže používám HT potrubí a specifické součástky jsem si vymodeloval a následně pomocí 3D tisku zhotovil. I když jsou materiály jiné, celková logika a funkce modelu zůstávají stejné jako u skutečné elektrárny.

14

## 2 Návrh a volba materiálů

Cílem této kapitoly bylo poukázat na různorodost materiálů použitelných pro tento projekt a vytvořit takový model, který by nebyl jen statickou maketou, ale robustním zařízením, které se dá snadno rozebrat a reálně na něm měřit účinnost motorů nebo generované napětí.

### 2.1 Koncepce modelu

Základní vizí byla modularita. Místo lepení bylo jako skelet použito HT potrubí . Jde o levný a lehký materiál, který díky hrdlovým spojům s těsněním drží skvěle u sebe. Celá elektrárna se tak dá kdykoliv rozebrat, což je ideální pro transport nebo ukázku vnitřního uspořádání. Za hlavní „strojovnu“ (gondolu) posloužil HT T-kus, který přirozeně vyřešil uložení motorů i vyvedení kabeláže dolů do věže.

### 2.2 Návrh 3D komponent

Pro tisk vnitřních lůžek byl zvolen materiál PET (polyethylentereftalát). I když je v amatérském 3D tisku častější jeho modifikace PETG (polyethylentereftalát glykol), čistý PET byl vybrán pro své specifické vlastnosti:

Mechanická tuhost: Čistý PET je oproti své modifikované verzi (PETG) o něco tužší a

má vyšší pevnost v tahu. To je v mém projektu výhodou, protože lůžka musí pevně a bez deformací držet DC motory i při vyšších otáčkách a vibracích.

Tepelná stabilita: PET má dobrou tepelnou odolnost, což zamezuje deformaci lůžek vlivem tepla vznikajícího na plášti motorů při dlouhodobém měření.

Tolerance a vlisování: Vzhledem k vyšší tvrdosti materiálu bylo nutné velmi přesně odladit

15 tiskové tolerance pro vlisování (press-fit). Zatímco měkčí materiály by drobné nepřesnosti „odpustily“ deformací, u PETu bylo nutné dosáhnout přesnosti na desetiny milimetru, aby lůžko v HT trubce sedělo pevně, ale zároveň neprasklo.

Vnější průměr lůžek jsem nastavil s přídavkem 0,2 mm oproti naměřenému vnitřnímu průměru trubky. Tím vznikl spoj, který drží skelet čistě mechanicky (třením). Samotné motory jsou pak k těmto 3D tištěným lůžkům pevně přišroubovány. Toto kombinované řešení zajišťuje, že se motor v uložení neprotočí ani při vysokém točivém momentu, a zároveň je celá sestava v HT trubce stabilní.

Modely všech součástek jsem navrhoval v softwaru Autodesk Inventor - Obrázek 2.1. Zaměřil jsem se především na vnitřní geometrii lůžek, která musela přesně odpovídat přírubám motorů a pozicím pro upevňovací šrouby, a na vnější rozměry, aby sestava přesně lícovala s vnitřkem HT T-kusu.

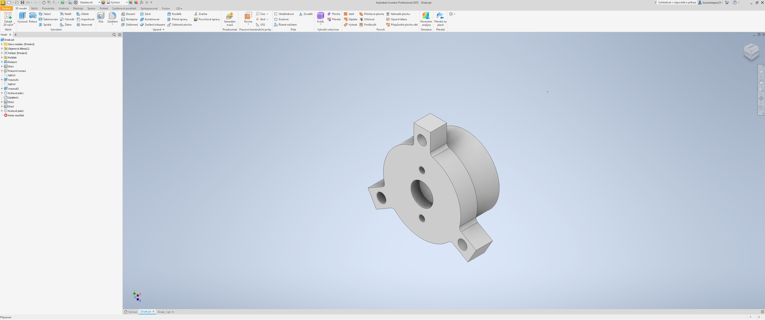
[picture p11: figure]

Obrázek 2.1: Prostředí autodesk inventor

### 2.3 Specifikace motorů

Srdcem modelu jsou tři stejnosměrné (DC) motory. Pro klíčové části systému – tedy výkonové soustrojí – jsem zvolil motory typu QSX-545, zatímco pro pohon samotného rotoru byl využit kompaktní převodový motor RF12-002. Tyto jednotky byly vybrány pro svou stabilitu, což je vlastnost nezbytná pro simulaci reálného energetického provozu.

16

V modelu jsou motory rozděleny do dvou odlišných funkčních celků:

- Vizuální pohon rotoru (Motor A): Jedná se o mikromotor s integrovanou planetovou převodovkou. Na rozdíl od hlavních motorů je zde kladen důraz na nízké výstupní otáčky (30 RPM) a vysoký krouticí moment. Tato volba umožňuje věrně simulovat plynulou rotaci skutečné turbíny. Motor disponuje hřídelí typu D-shaft, což zajišťuje pevné spojení s nábojem rotoru bez rizika prokluzu.
Parametr | Hodnota (RF12-002)
Jmenovité napětí | 12 V DC
Otáčky naprázdno | 30 RPM
Proud naprázdno | 0,08 A
Maximální proud pod zátěží | 0,1 A
Rozměry těla (délka × průměr) 34 mm × 12 mm
Průměr hřídele | 2,5 mm
Délka hřídele | 10 mm
Osa | typu D

Tabulka 2.1: Technické specifikace hlavních motorů soustrojí

- Výkonové soustrojí (Motory B a C): V zadní části gondoly se nachází dvojice motorů QSX-545 v konfiguraci „motor-generátor“. Jeden motor slouží jako pohon (simulátor větrné síly) a druhý jako generátor elektrické energie. Vzhledem k vysokému odběru (až 2,5 A) je soustrojí napájeno stabilizovaným PC zdrojem Dell.
Parametr | Hodnota (QSX-545)
Jmenovité napětí | 12 V DC
Otáčky naprázdno | 7000 RPM
Proud naprázdno | 0,3 A
Maximální proud pod zátěží | 2,5 A
Rozměry těla (délka × průměr) 55 mm × 35 mm
Průměr hřídele | 3,17 mm
Délka hřídele | 6 mm
Osa | typu O

Tabulka 2.2: Technické specifikace hlavních motorů soustrojí

17

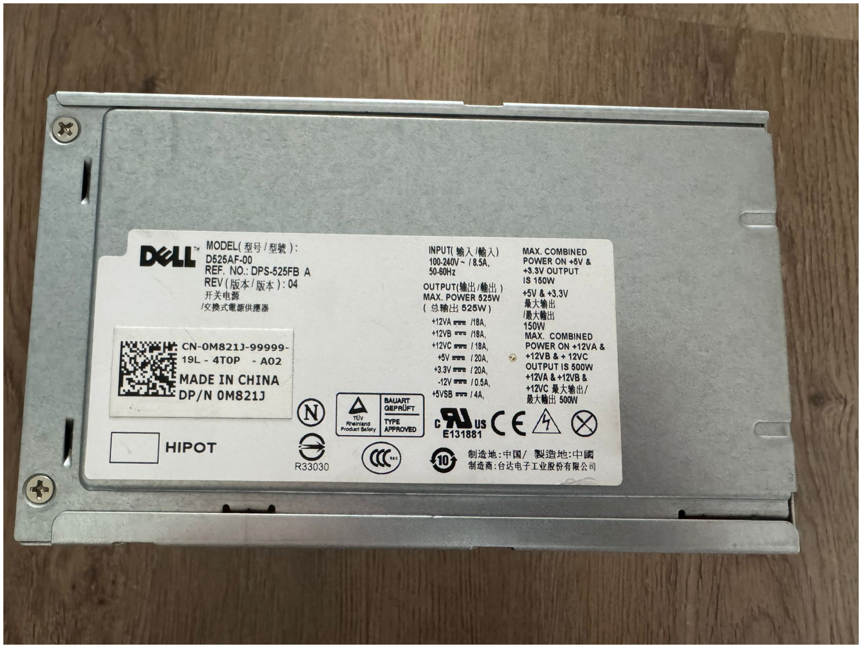
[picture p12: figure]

Obrázek 2.2: Zdroj Dell

### 2.3.1 Konstrukce „strojní klece“

Pro zajištění maximální přesnosti měření účinnosti mezi motory B a C bylo nutné navrhnout řešení, které udrží hřídele v dokonalé ose a zamezí vzniku nežádoucích sil. K tomuto účelu jsem navrhl tzv. „strojní klec“ - Obrázek 2.3 . Konstrukce je tvořena soustavou šesti ocelových šroubů M5, které procházejí 3D tištěnými lůžky motorů a jsou vzájemně propojeny distančními (spojovacími) maticemi.

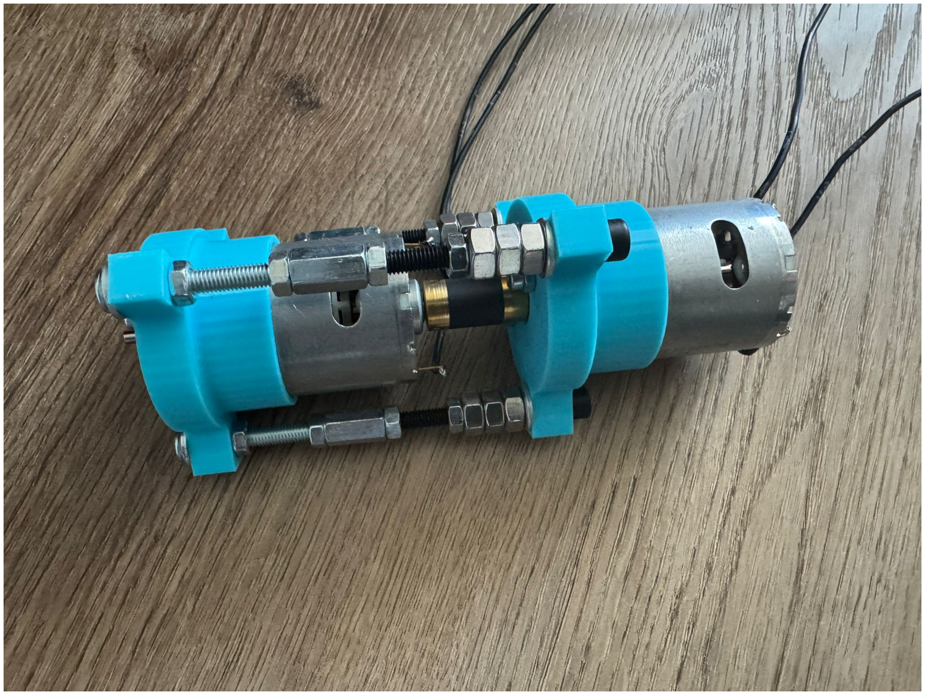
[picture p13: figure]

Obrázek 2.3: Sestava motorů

Toto řešení přináší zásadní technické výhody:

18

1. Vysoká mechanická stabilita a souosost: Použití šesti fixačních bodů namísto běžných dvou zajišťuje, že se lůžka motorů vůči sobě nepohnou ani při vysokém točivém momentu. Tento tuhý skelet udržuje motory v konstantní ose, čímž se minimalizuje radiální tření, které by jinak mělo vliv na velikost točivého momentu a následně výsledky měření.
2. Jemná kalibrace rozteče: Díky spojení šroubů pomocí distančních matic lze milimetrově nastavit vzdálenost mezi motory. To je kritické pro správné předpětí pružné spojky – ta nesmí být axiálně přetěžována, aby nedocházelo k nadměrnému opotřebení ložisek motorů QSX-545.
3. Eliminace vibrací: Šestibodové uchycení tvoří extrémně tuhý mechanický ce-

lek, který efektivně pohlcuje nežádoucí vibrace vznikající při vysokých otáčkách (7000 ot/min). Tím se předchází předčasnému zahřívání komponentů.

4. Modularita a údržba: Tato „stavebnicová“ konstrukce umožňuje klec kdykoliv rozebrat, vyjmout motory nebo upravit celkovou délku v případě výměny spojky za jiný typ.

Kromě fixace v této kleci jsou všechny motory ke svým 3D tištěným lůžkům navíc pevně přišroubovány, aby se zamezilo jejich protočení uvnitř skeletu z HT trubek. Celý systém tak tvoří stabilní a přesnou laboratorní jednotku pro testování účinnosti přenosu energie.

19

## 3 Technická realizace

V této kapitole jsem se zaměřil na proces výroby navržených komponent a následnou kompletaci celého modelu větrné elektrárny.

### 3.1 Příprava nosné konstrukce

Základ celého skeletu je HT potrubí. Využil jsem přesných rozměrů standardizovaných trubek a upravil je pro potřeby modelu elektrárny, zvolil jsem tedy postup „výroby na míru“:

- Měření skeletu: Nejdříve jsem přesně změřil vnitřní průměry všech použitých HT prvků (T-kus, trubky) pomocí posuvného měřítka.
- Zvýšení tuhosti věže: Vzhledem k výšce modelu a hmotnosti gondoly s motory bylo nutné zajistit maximální stabilitu vertikálního tubusu. Do vnitřního prostoru hlavní HT trubky (nohy) byla proto vlisována vložka z tuhého tvrzeného kartonu. Tato vnitřní výztuha výrazně zvyšuje odolnost konstrukce proti ohybu a vibracím, aniž by došlo k nežádoucímu nárůstu celkové hmotnosti.
- Iterace v Inventoru: Naměřené hodnoty (včetně vnitřního průměru s vloženou výztuhou) jsem následně promítl zpět do modelů lůžek. Právě díky tomuto kroku jsem mohl nastavit přesný přesah pro vlisování.
- Úprava potrubí: Trubky (rotoru) byly zaříznuty a tvarově upraveny, aby odpoví-

daly reálným poměrům velikostí vůči celkové sestavě.

20

### 3.2 Proces 3D tisku

I když tisk dílů z materiálu PET probíhal externě, finální lícování a osazování komponentů jsem prováděl sám.

- Montáž motorů do lůžek: Každý motor byl nejdříve vložen do svého lůžka a následně pevně přišroubován - obrázky 3.1 3.2. Tento krok byl zásadní pro přenos točivého momentu – vlisování (press-fit) sice drží lůžko v trubce, ale šrouby zaručují, že se motor v lůžku ani nepohne.
- Sestavení výkonového okruhu: U zadní dvojice motorů jsem využil systém závitových tyčí. Ty procházejí otvory v lůžkách a pomocí matic umožňují milimetrově přesné nastavení vzdálenosti mezi oběma motory.
- Propojení hřídelí: Mezi hřídele zadních motorů jsem použil pružnou polymerovou spojku. Ta funguje jako jednoduchý kardan a vyrovnává drobné nepřesnosti v souososti, které by jinak způsobovaly zbytečné tření.

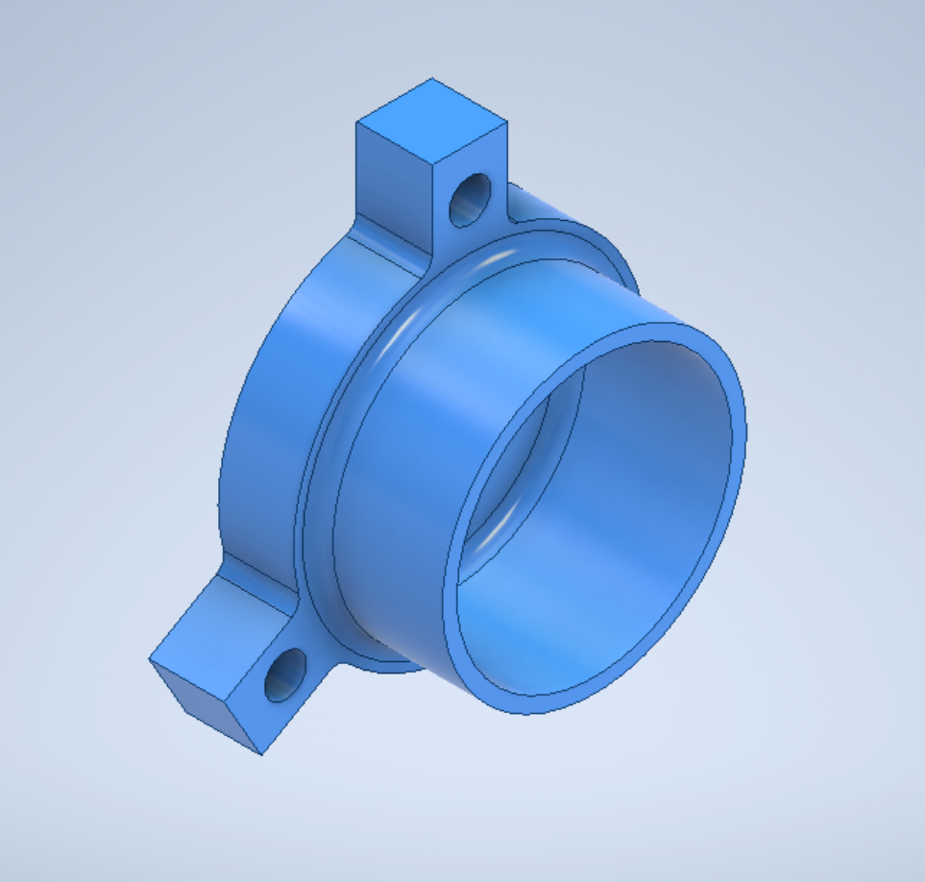
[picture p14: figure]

Obrázek 3.1: Lůžko pro motor QSX 545

### 3.3 Montáž komponent a management kabeláže

Proces finální montáže byl rozdělen do několika logických etap, které musely být dodrženy pro zajištění souososti rotačních částí a bezpečného vedení elektroinstalace.

21

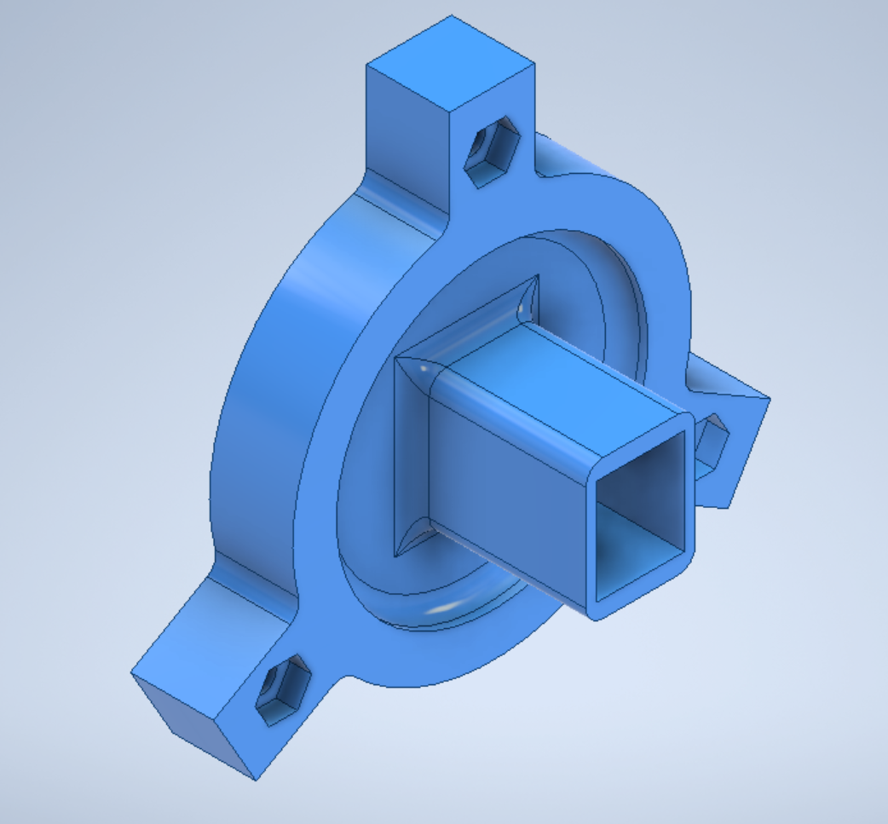
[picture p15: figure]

Obrázek 3.2: Lůžko pro motor RF12-002

- Lisování vnitřních sestav: Nejdříve byly do ramen HT T-kusu (gondoly) vlisovány předpřipravené sestavy motorů s lůžky. Jelikož materiál PET disponuje vysokou tuhostí, bylo nutné využít rovnoměrný tlak, aby nedošlo k vyosení motoru vůči ose trubky. Těsné uložení (press-fit) zaručuje, že vibrace vznikající při vysokých otáčkách nevedou k postupnému uvolnění motorů.
- Vnitřní vedení kabeláže: Kritickým bodem návrhu bylo bezpečné vedení vodičů. Vnitřní prostor HT potrubí slouží jako chránička. Vodiče od předního generátoru i zadní výkonové dvojice jsou svedeny do středu T-kusu a následně protaženy kolmo dolů skrze hlavní tubus (věž). Toto řešení eliminuje jakékoliv riziko namotání kabelů na hřídele motorů a zároveň chrání izolaci před vnějšími vlivy.
- Propojení se základnou: Vodiče z věže prochází základovou deskou (OSB deskou). Toto uspořádání umožňuje snadné připojení multimetrů a externího napájecího zdroje Dell, aniž by docházelo k namáhání pájených spojů na samotných motorech při manipulaci s modelem.
- Zajištění spojů: Ačkoliv hrdlové spoje HT systému drží díky těsnění pevně, byly klíčové body spojení tubusu s gondolou dodatečně kontrolovány na svislost, aby osa rotoru byla v přesné horizontální rovině.

22

### 3.4 Konstrukce testovacího podstavce

Aby byl model při měření stabilní a nedocházelo k jeho převrácení vlivem rotace nebo vibrací motorů, vyrobil jsem pro něj pevnou základnu.

- Materiál základny: Jako hlavní desku jsem zvolil OSB desku, která má dostatečnou plochu a hmotnost. K ní jsou pomocí vrutů připevněny dřevěné latě, které tvoří spodní část podstavce a prostor pro kabeláž.
- Fixace skeletu: Noha elektrárny je fixována k OSB desce přišroubovanou HT zátkou. Toto řešení vytváří pevnou testovací základnu, která simuluje reálné ukotvení věže elektrárny.
- Uspořádání komponent: Na desce je kromě samotného modelu vyhrazen i prostor pro umístění zdroje.

### 3.5 Finální úpravy gondoly a aerodynamické doplňky

Poslední fáze montáže byla zaměřena na detaily, které zlepšují aerodynamiku modelu a esteticky zakončují hrubou konstrukci z HT trubek.

- Aerodynamický kryt náboje (Spinner): Přední část rotoru, kde se nachází upevnění listů, byla upravena pomocí polyuretanové pěny. Tato hmota vyplnila prostor náboje a po vytvrdnutí umožnila vytvarovat hladký, zaoblený „nos“ elektrárny. Tento prvek je klíčový pro plynulé obtékání vzduchu kolem gondoly a snižuje turbulence přímo před listy rotoru.
- Zakončení strojovny: Pro estetické a funkční uzavření zadní části T-kusu jsem využil netradiční, ale efektivní prvek – upravený papírový kelímek, a to pro jeho kónický tvar a průměr, který přesně pasuje na zakončení T-kusu a tvoří přirozené zakončení gondoly.

23

- Výhoda odnímatelnosti: Velkým přínosem kelímku je jeho snadná demontovatelnost. To umožňuje okamžitý přístup k zadní dvojici motorů, pružné spojce a závitovým tyčím bez nutnosti rozebírat celý skelet. Papírový materiál je navíc lehký, nezatěžuje konstrukci a v případě potřeby (např. při instalaci chlazení) do něj lze snadno vyřezat ventilační otvory.

### 3.6 Výroba listů rotoru

Listy rotoru (vrtule) jsou klíčovým prvkem pro zachycení energie větru. Místo nákupu hotových komponentů jsem se rozhodl pro vlastní výrobu z dostupného materiálu, který umožnil experimentovat s tvarem.

- Příprava polotovaru: Jako základ posloužila standardní plastová HT trubka. Tu jsem podélně rozřízl, čímž vznikly surové segmenty pro jednotlivé listy.
- Tvarování: Aby listy měly optimální aerodynamický profil (prohnutí), využil jsem metodu tepelného tvarování. Materiál jsem lokálně nahřál horkovzdušnou pistolí do stavu plasticity a následně jej vytvaroval pomocí improvizovaného tvarovacího přípravku – skleněné láhve. Její rádius zajistil listům rovnoměrné a plynulé zakřivení, které je důležité pro vznik vztlaku.
- Finální opracování: Po vychladnutí a vytvrdnutí plastu jsem pomocí úhlové brusky upravil listy do výsledného kapkovitého tvaru. Hrany byly následně začištěny jemným brusným papírem, aby se snížil odpor vzduchu a hluk při rotaci.

24

## 4 Princip funkčnosti a ověření

V této kapitole popisuji metodiku měření efektivity celého systému. K měření jsem využil laboratorní sestavu dvou motorů propojených hřídelemi, což umožňuje přesné stanovení ztrát bez vlivu nestability přírodního větru.

### 4.1 Systém přenosu

Aby bylo možné provádět měření v laboratorních podmínkách (v interiéru), bylo nutné vyřešit náhradu kinetické energie větru konstantním a regulovatelným pohonem.

- Využití PC zdroje (PSU): Pro napájení hnací části jsem zvolil spínaný zdroj značky Dell. Jeho hlavní výhodou oproti běžným adaptérům je vysoká proudová zatížitelnost a precizní filtrace výstupního napětí. Využívám především větev 12V pro jmenovitý výkon motoru, 5V pro pohon 3. motoru (demonstrace otáčení rotoru) a 3,3V pro testování při nižších otáčkách. Stabilita tohoto zdroje zaručuje, že kolísání naměřených hodnot na výstupu není způsobeno nekvalitním napájením, ale reálnými fyzikálními procesy v soustrojí. Zdroj jsem upravil přídavným spínačem pro spínání zdroje.
- Hnací motor (Simulátor větru): Tento motor přebírá roli větrného proudu. Elektrická energie ze zdroje je v něm přeměněna na točivý moment, který je přes pružnou spojku přenášen na hřídel generátoru. Změnou napájecích větví (nebo zařazením regulátoru) mohu simulovat různé rychlosti větru a sledovat, jak se mění účinnost přenosu při různých otáčkách.
- Generátor (Energetický výstup): Druhý motor v sérii pracuje v inverzním režimu. Mechanická energie z hnacího hřídele v něm indukuje elektrický proud. Tento

25

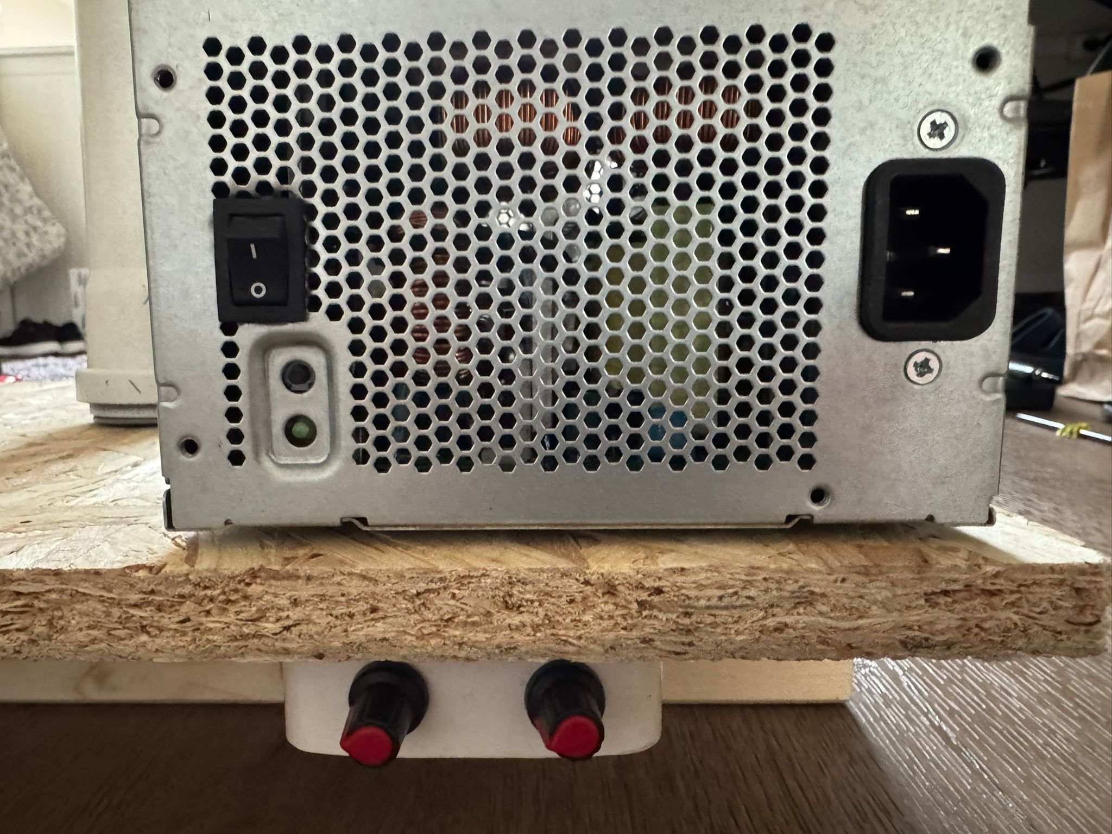
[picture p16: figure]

Obrázek 4.1: Upravený zdroj s regulátory

"druhotný"elektrický výkon je následně vyveden na měřicí svorky. Porovnáním příkonu hnacího motoru a výkonu tohoto generátoru získáváme přesný obraz o účinnosti celé mechanické sestavy.

### 4.2 Experimentální měření

Vlastní měření probíhalo v kontrolovaných podmínkách testovací základny. Cílem bylo zjistit, jak efektivně dokáže soustava přenést energii z hnacího motoru na generátor přes pružnou polymerovou spojku.

- Vstupní parametry: Jako zdroj napětí byl použit PC zdroj Dell, přičemž pro hlavní test byla zvolena větev 12 V. Toto napětí simuluje stabilní, silný vítr působící na rotor elektrárny.
- Průběh testu: Po rozběhu soustavy a stabilizaci otáček bylo digitálním multimetrem UT33D naměřeno napětí na výstupních svorkách generátoru.
- Naměřená hodnota: Při vstupním napětí Uin = 12 V bylo na výstupu generátoru naměřeno napětí Uout = 10, 01 − 10, 08 V.

26

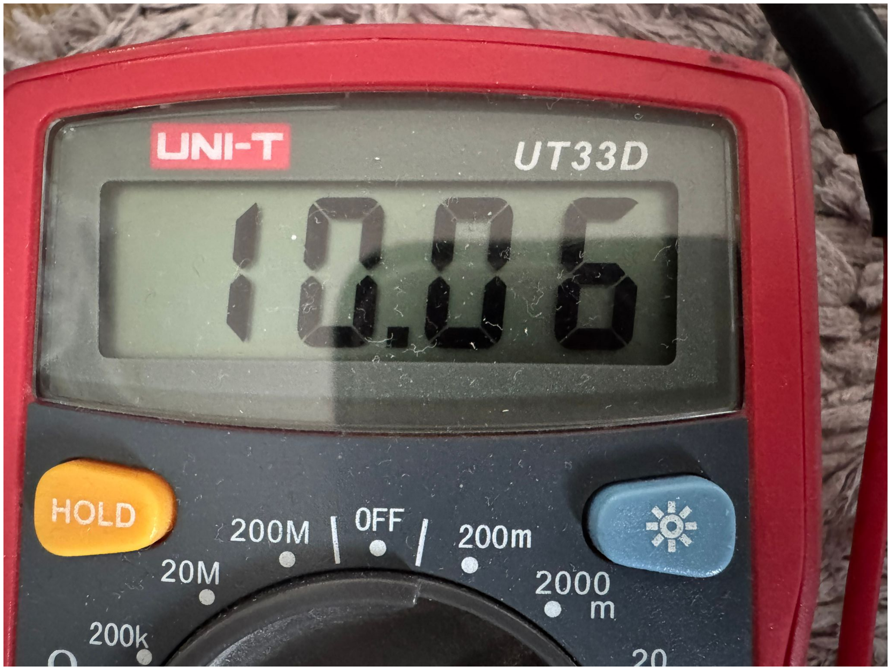
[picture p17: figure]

Obrázek 4.2: Multimetr - Uout

### 4.3 Analýza účinnosti

Z naměřených hodnot lze vyvodit závěry o efektivitě přenosu. Pokud bychom uvažovali o ideálním bezeztrátovém systému, napětí na výstupu by odpovídalo napětí na vstupu. V reálném modelu však dochází k poklesu, který v tomto případě činí přibližne 1, 94 V.

Výpočet napěťové účinnosti (ηu): Pro hrubý odhad efektivity mechanického přenosu

využijeme poměr napětí:

ηu =

Uout

Uin

=

10, 06
12, 00

.= 0, 8383 =⇒ 83, 83 %

Zdůvodnění ztrát: I přes velmi slušnou účinnost přesahující 83, 83 % dochází ke ztrátám, které jsou způsobeny následujícími faktory:

1. Mechanické odpory a síly: I přes použití pružné polymerové spojky, která má za úkol eliminovat drobné odchylky v souososti, vznikají při rotaci tzv. radiální síly. V řádech desetin milimetru se může zdát nesouosost zanedbatelná, ale při vyšších otáčkách způsobuje cyklické namáhání ložisek. To vede ke zvýšenému tření mezi kuličkami a drahami ložiska, kde se část mechanické energie nevratně mění v teplo.
2. Elektromagnetické a ohmické ztráty: Tento faktor je dán vnitřní konstrukcí DC motorů.

27

- Jouleovo teplo: Průchodem proudu přes odpor měděného vinutí (R) vznikají tepelné ztráty definované vztahem P = R · I

2
- Vířivé proudy: Při otáčení rotoru v magnetickém poli vznikají v železném jádře nechtěné vířivé proudy, které jádro zahřívají. Právě tyto ztráty způsobují, že napětí na generátoru je vždy nižší než napětí ideálního zdroje.
3. Aerodynamický odpor a ventilační ztráty: I když jsou motory uzavřeny v plášti, vnitřní rotor s vinutím a komutátorem funguje při vysokých otáčkách jako malý ventilátor. Musí neustále "rozrážet"vzduch uvnitř statoru. Tento odpor roste s druhou mocninou rychlosti otáčení, což znamená, že čím rychleji hnací motor točí generátorem, tím větší část výkonu se spotřebuje jen na překonání tohoto vnitřního odporu vzduchu.

28

## Závěr

Cílem této práce bylo navrhnout a realizovat funkční laboratorní model větrné elektrárny s horizontální osou rotace (HAWT), který by sloužil k demonstraci energetických přeměn a měření účinnosti přenosu síly.

Během realizace bylo nutné vyřešit řadu technických výzev. Jako nejvhodnější materiál pro šasi se ukázalo modifikované HT potrubí, které v kombinaci s vnitřní kartonovou výztuhou poskytuje dostatečnou tuhost při zachování nízké hmotnosti. Klíčovým prvkem projektu se stala integrace 3D tištěných dílů z materiálu PETG. Díky iterativnímu přístupu v prostředí Autodesk Inventor se podařilo dosáhnout vysoké přesnosti uložení všech komponentů.

Největší přínos konstrukce spatřuji v návrhu a výrobě tzv. „strojní klece“ pro měřicí soustrojí. Toto řešení, využívající systém šesti ocelových šroubů a distančních matic, zajistilo dokonalou souosost hnacího motoru a generátoru QSX-545 i při vysokých otáčkách dosahujících 7000 ot/min. Právě díky této mechanické stabilitě bylo možné eliminovat parazitní tření a získat relevantní data o napěťové účinnosti systému, která při testování dosahovala hodnot kolem 85 %.

Vizuální stránka modelu byla podpořena použitím mikromotoru s planetovou převodovkou pro pohon listů rotoru, což umožnilo věrnou simulaci plynulého chodu reálné turbíny. Celý systém je napájen upraveným PC zdrojem Dell, který spolehlivě pokrývá vysoké proudové nároky soustrojí pod zátěží.

Tento model potvrzuje, že s využitím moderních metod (3D tisk, CAD modelování) a dostupných průmyslových materiálů lze vytvořit přesné a stabilní měřicí zařízení. Práce může v budoucnu sloužit jako základ pro další studium aerodynamiky listů rotoru nebo pro testování pokročilejších typů generátorů.

29

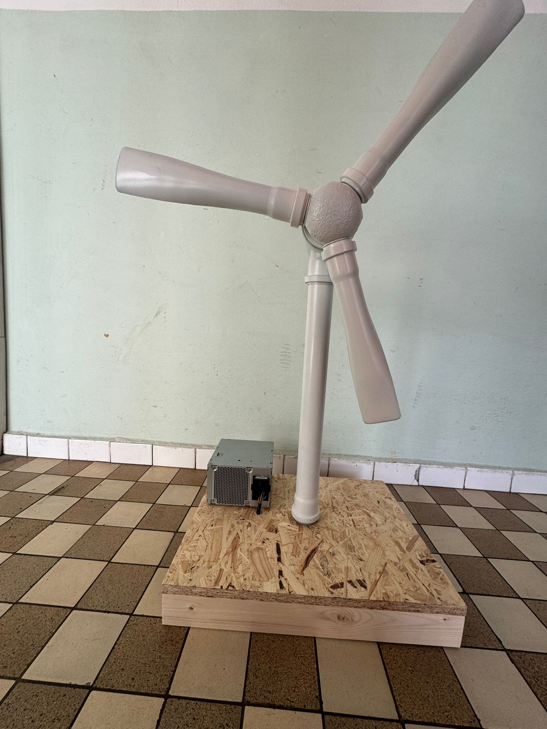
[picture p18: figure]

Obrázek 4.3: Model větrné elektrárny

30

## Seznam použité literatury a zdrojů

### Literatura

[1] KRÁLÍK, Jaroslav. Energie větru: principy, technologie, využití. 1. vyd. Praha: BEN

– technická literatura, 2008, 128 s. ISBN 978-80-7300-234-2.

[2] MIKULČÁK, Jiří. Matematické, fyzikální a chemické tabulky pro střední školy.
3. vyd. Praha: Prometheus, 1997, 206 s. ISBN 80-85849-84-4.

### Internetové zdroje

[3] AUTODESK. Autodesk Inventor Help: Parametric Part Design. Autodesk Knowledge Network [online]. Copyright © 2026 [cit. 27.04.2026]. Dostupné z:

https://knowledge.autodesk.com

[4] PRŮŠA, Josef. 3D tisk pro začátečníky. Prusa Research [online]. Copyright

© 2018 [cit. 27.04.2026]. Dostupné z: https://www.prusa3d.com/cs/stranka/

3d-tisk-pro-zacatecniky_29/ (https://www.prusa3d.com/cs/stranka/3d-tisk-pro-zacatecniky_29/)

[5] ESP32 Pinout Reference: Which GPIO pins should you use? | Random Nerd Tutori-
als. Random Nerd Tutorials [online]. Copyright © 2013 [cit. 27.04.2026]. Dostupné

z: https://randomnerdtutorials.com/esp32-pinout-reference-gpios/

[6] DELL. Power Supply Unit Specifications and Pinout. Dell Support [online]. [cit. 27.04.2026]. Dostupné z: https://www.dell.com/support/
[7] TECHFUN.CZ. DC motorek s převodem – různé typy. Techfun.cz – elektronika pro vaše projekty [online]. [cit. 27.04.2026]. Dostupné z: https://techfun.cz/

produkt/dc-motorek-s-prevodem-ruzne-typy/ (https://techfun.cz/produkt/dc-motorek-s-prevodem-ruzne-typy/)

31

[8] TECHFUN.CZ. Motorek 12V QSX-545. Techfun.cz – elektronika pro vaše projekty [online]. [cit. 27.04.2026]. Dostupné z: https://techfun.cz/produkt/

motorek-12v-qsx-545/ (https://techfun.cz/produkt/motorek-12v-qsx-545/)

[9] LASKA KIT. PWM regulátor otáček motoru 5A. LaskaKit.cz – e-shop pro bastlíře [online]. [cit. 27.04.2026]. Dostupné z: https://www.laskakit.cz/

pwm-regulator-otacek-motoru-5a/ (https://www.laskakit.cz/pwm-regulator-otacek-motoru-5a/)

[10] GOOGLE. Gemini (model Gemini 1.5 Flash). Google AI [online]. [cit. 27.04.2026].

Dostupné z: https://gemini.google.com/

32

## Přílohy

Příloha I: Lůžko motoru QSX 545.idw (elektronicky)

Příloha II: Lůžko motoru RF12-002.idw (elektronicky)

Příloha III: Lůžko motoru QSX 545.ipt (elektronicky)

Příloha IV: Lůžko motoru RF12-002.ipt (elektronicky)

I

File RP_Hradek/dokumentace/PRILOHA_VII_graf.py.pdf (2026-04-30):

import serial
import time
import matplotlib.pyplot as plt

PORT = "COM3"
BAUD = 115200

ser = serial.Serial(PORT, BAUD, timeout=1)

times = []
values = []
start = time.time()

plt.ion()

fig, ax = plt.subplots()
line, = ax.plot([], [], marker="o", label="Napětí")

ax.set_title("Napětí v čase")
ax.set_xlabel("Čas [s]")
ax.set_ylabel("Napětí [V]")
ax.set_ylim(0, 20)
ax.grid(True)
ax.legend()

info_text = ax.text(
0.02,
0.95,
"",
transform=ax.transAxes,
verticalalignment="top"
)

print("Čtu data...")

while True:
raw = ser.readline().decode(errors="ignore").strip()

if not raw:
plt.pause(0.05)
continue

try:
value = float(raw)
except ValueError:
plt.pause(0.05)
continue

t = time.time() - start

times.append(t)
values.append(value)

maximum = max(values)
minimum = min(values)
average = sum(values) / len(values)
print(f"{t:.1f}s | {value:.3f} V | max {maximum:.3f} | min {minimum:.3f} | avg
{average:.3f}")

line.set_data(times, values)

ax.set_xlim(max(0, t - 60), t + 1)

info_text.set_text(
f"Aktuálně: {value:.3f} V\n" f"Maximum: {maximum:.3f} V\n" f"Minimum: {minimum:.3f} V\n" f"Průměr: {average:.3f} V" )

fig.canvas.draw_idle()
plt.pause(0.1)

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
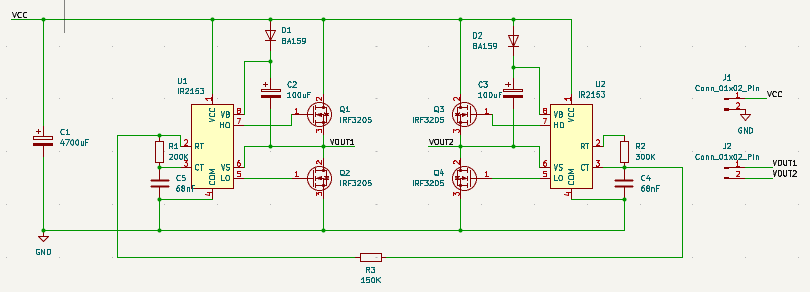
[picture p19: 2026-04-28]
RP_Hradek/reseni/H-mustek_(stridac)/stridac.png

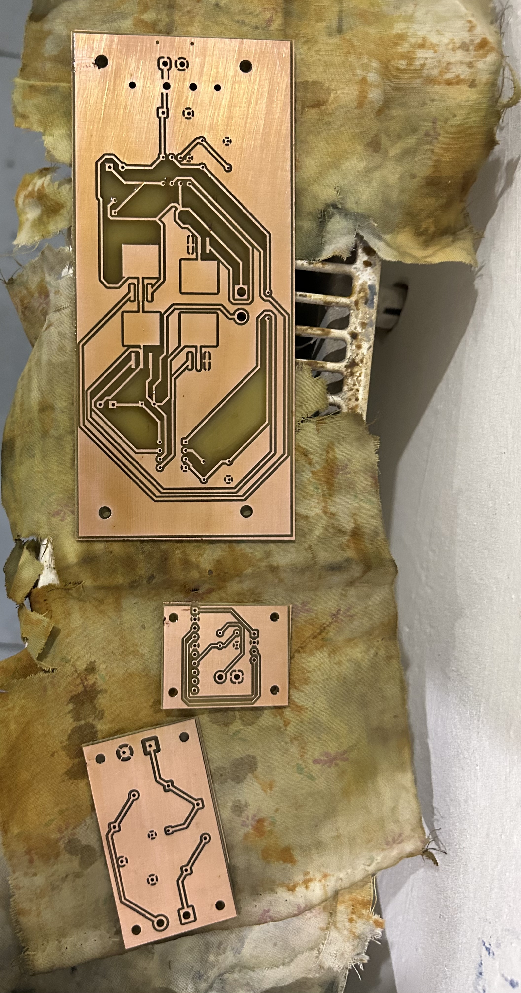
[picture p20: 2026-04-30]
RP_Hradek/reseni/real_fotky/desky.jpg

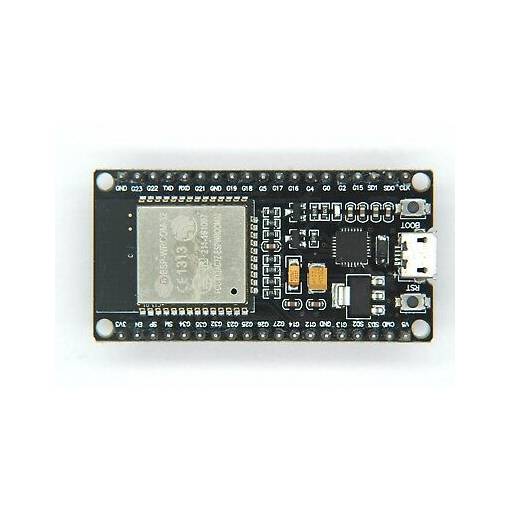
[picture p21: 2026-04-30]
RP_Hradek/reseni/esp32_prace/PRILOHA_X_esp32.png

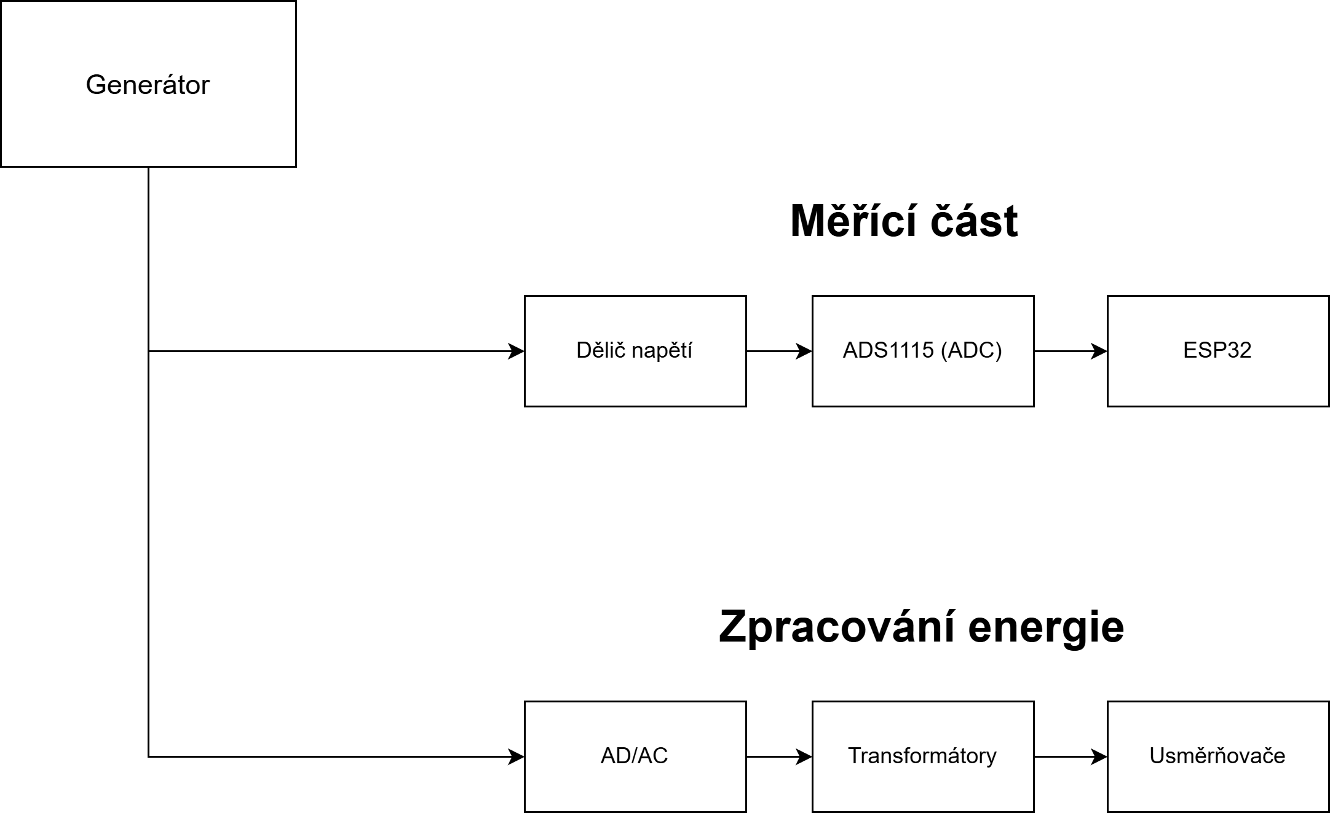
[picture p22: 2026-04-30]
RP_Hradek/reseni/navrh/PRILOHA_XI_blokove_schema.png

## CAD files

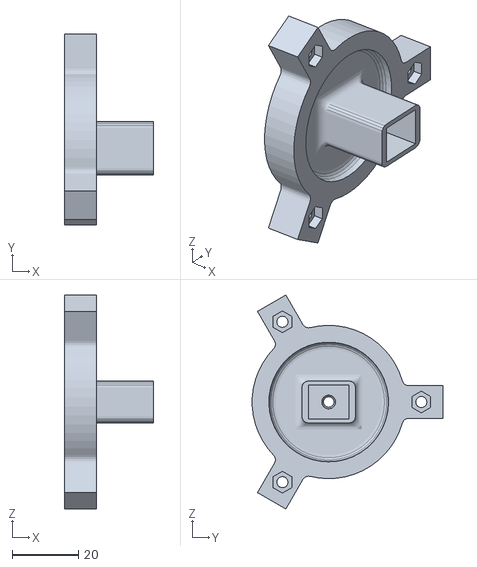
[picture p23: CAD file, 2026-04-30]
RP_Koznar/projektove_podklady/Lůžko motoru RF12-002.stl
26.9 x 57.6 x 64.7

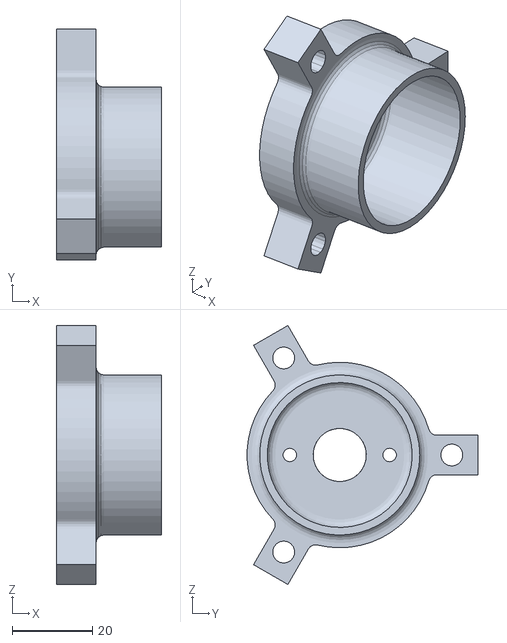
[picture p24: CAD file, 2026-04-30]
RP_Koznar/projektove_podklady/Lůžko motoru QSX 545.stl
26.3 x 57.6 x 64.7

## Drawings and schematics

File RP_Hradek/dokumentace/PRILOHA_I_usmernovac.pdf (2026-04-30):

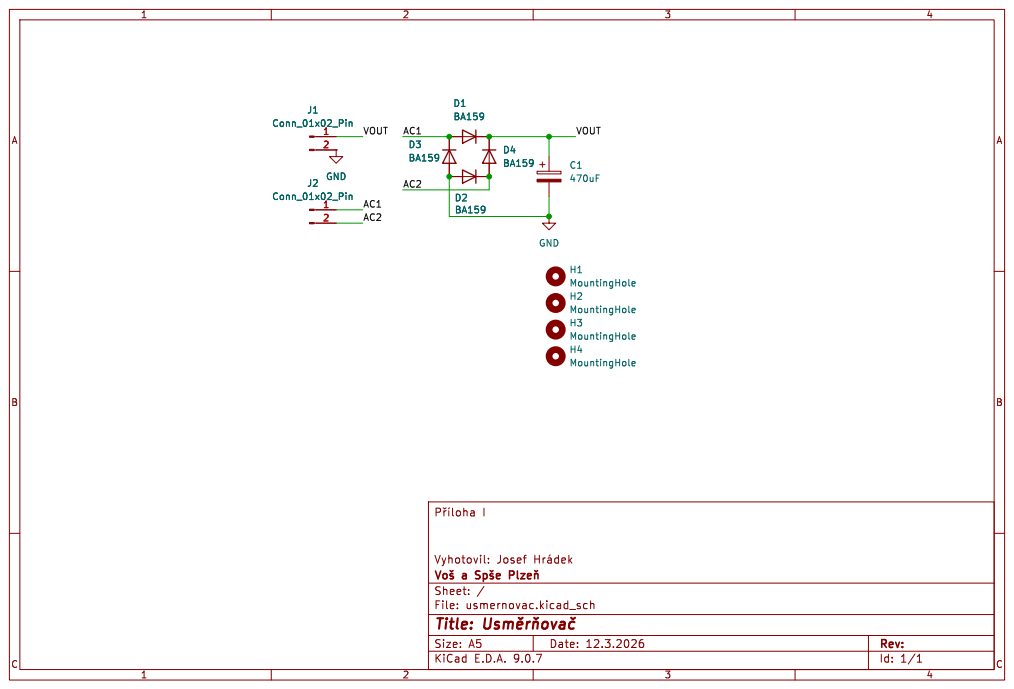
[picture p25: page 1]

Sheet: /
File: usmernovac.kicad_sch
Title: þÿUsmrHova

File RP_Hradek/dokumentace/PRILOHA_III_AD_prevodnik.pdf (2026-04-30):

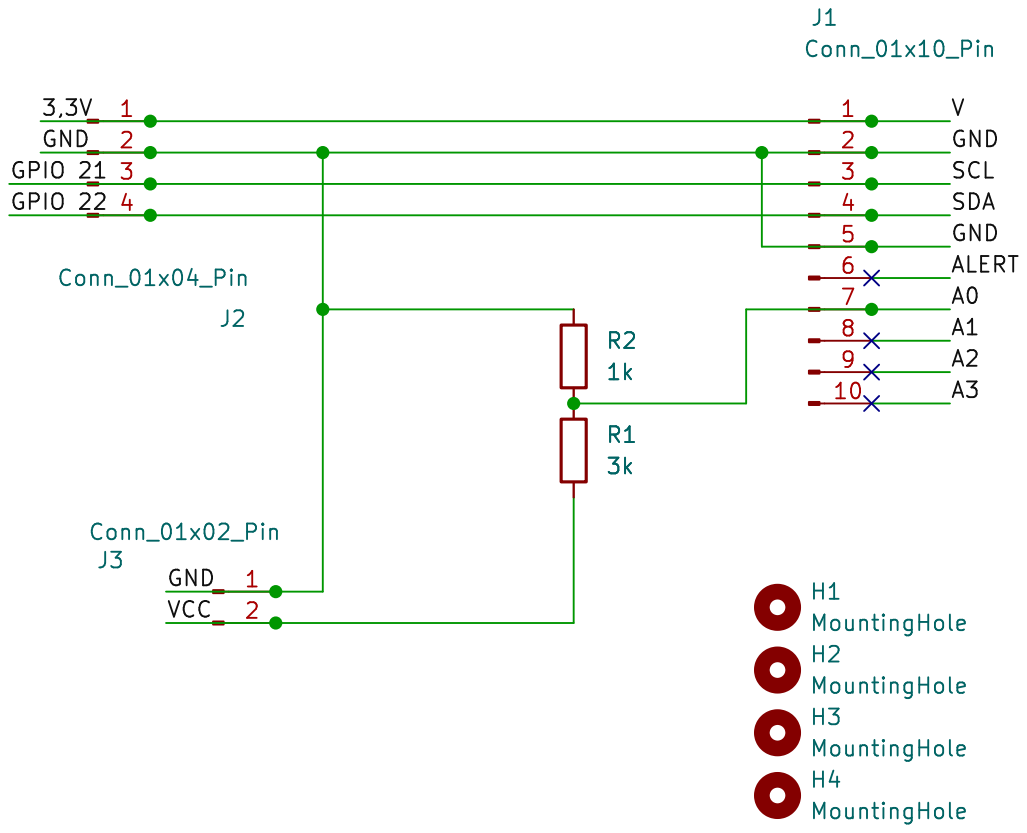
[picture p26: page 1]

File: AD_prevodnik.kicad_sch Sheet: / þÿVoaa þÿSpae þÿPlzeH

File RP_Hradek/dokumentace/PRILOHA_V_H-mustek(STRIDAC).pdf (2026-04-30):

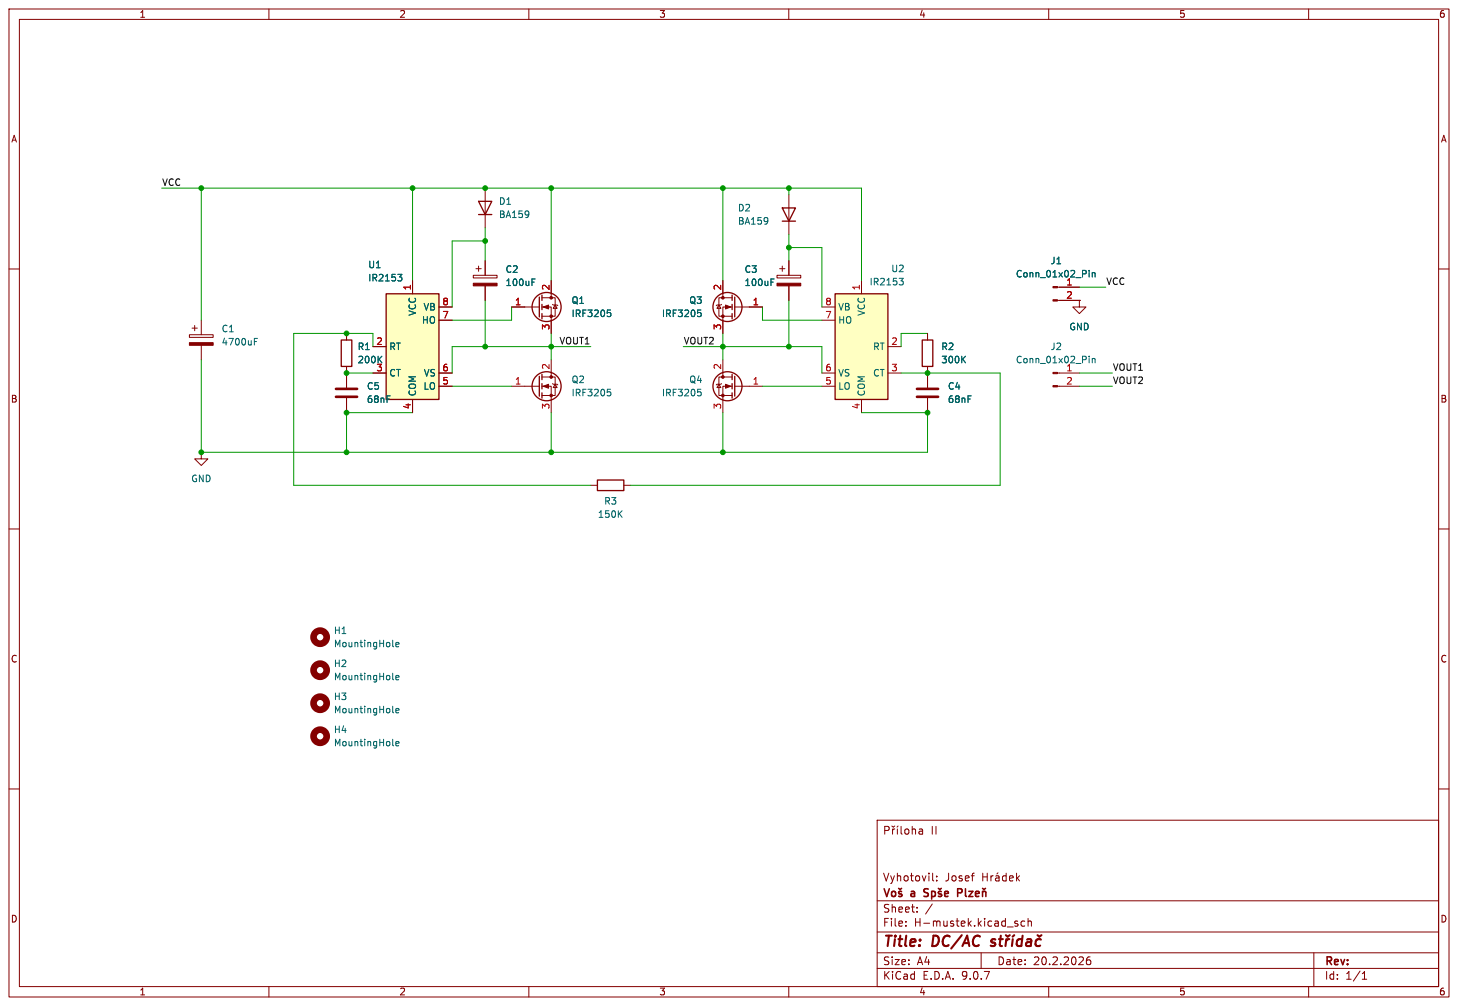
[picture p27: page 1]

150K H4 MountingHole H2 MountingHole H1 MountingHole H3 MountingHole

File: H-mustek.kicad_sch Sheet: / þÿVoaa þÿSpae þÿPlzeH

Id: 1/1 Title: DC/AC þÿstYída

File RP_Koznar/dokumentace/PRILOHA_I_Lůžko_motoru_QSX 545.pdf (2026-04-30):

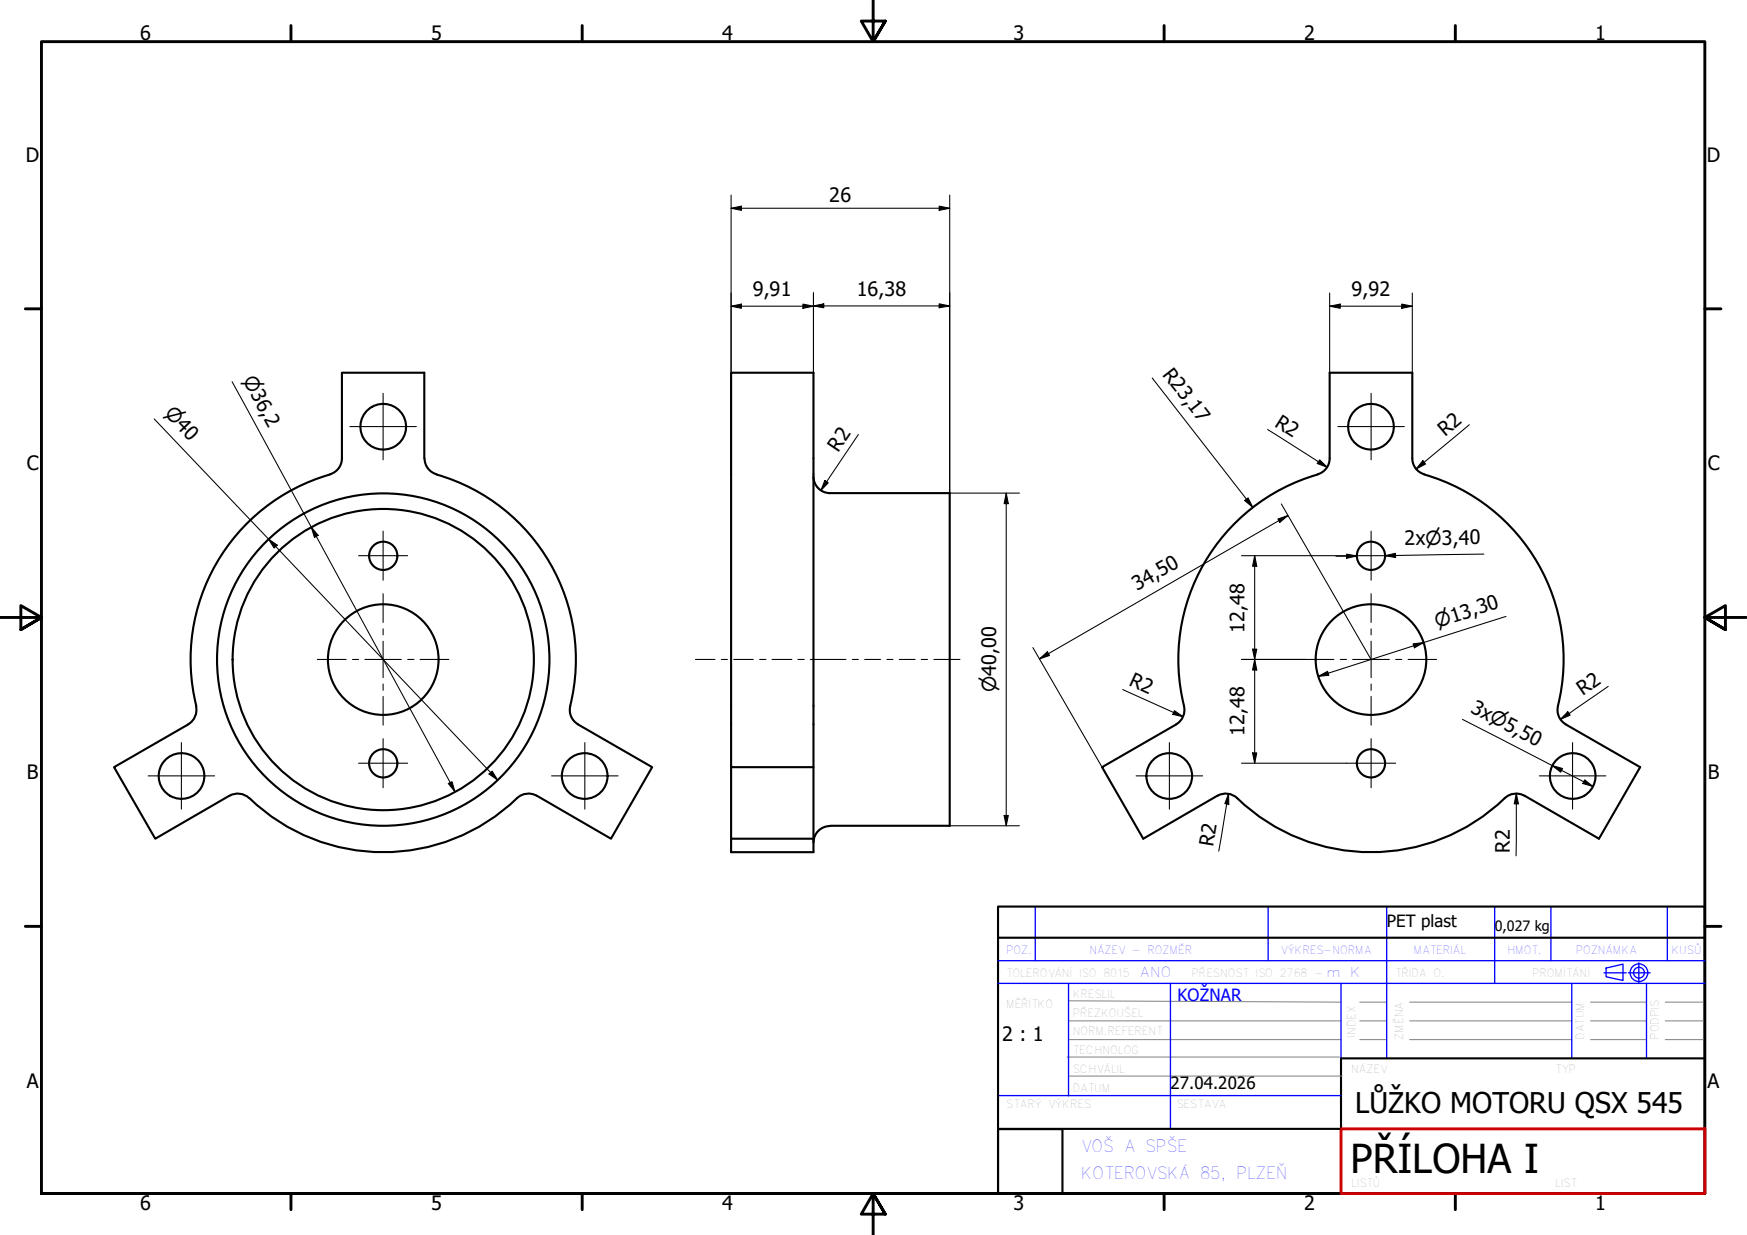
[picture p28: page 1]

PET plast | 0,027 kg

POZ. | NÁZEV - ROZMĚR | VÝKRES-NORMA | MATERIÁL | HMOT. | POZNÁMKA | KUSŮ

TOLEROVÁNÍ ISO 8015 ANO PŘESNOST ISO 2768 -m K | TŘÍDA O. | PROMÍTÁNÍ
MĚŘÍTKO 2 : 1 | KRESLIL | KOŽNAR

PŘEZKOUŠEL

NORM.REFERENT
TECHNOLOG
SCHVÁLIL | | NÁZEV TYP LŮŽKO MOTORU QSX 545
DATUM | 27.04.2026

STARÝ VÝKRES | | SESTAVA

VOŠ A SPŠE KOTEROVSKÁ 85, PLZEŇ | PŘÍLOHA I LISTŮ LIST

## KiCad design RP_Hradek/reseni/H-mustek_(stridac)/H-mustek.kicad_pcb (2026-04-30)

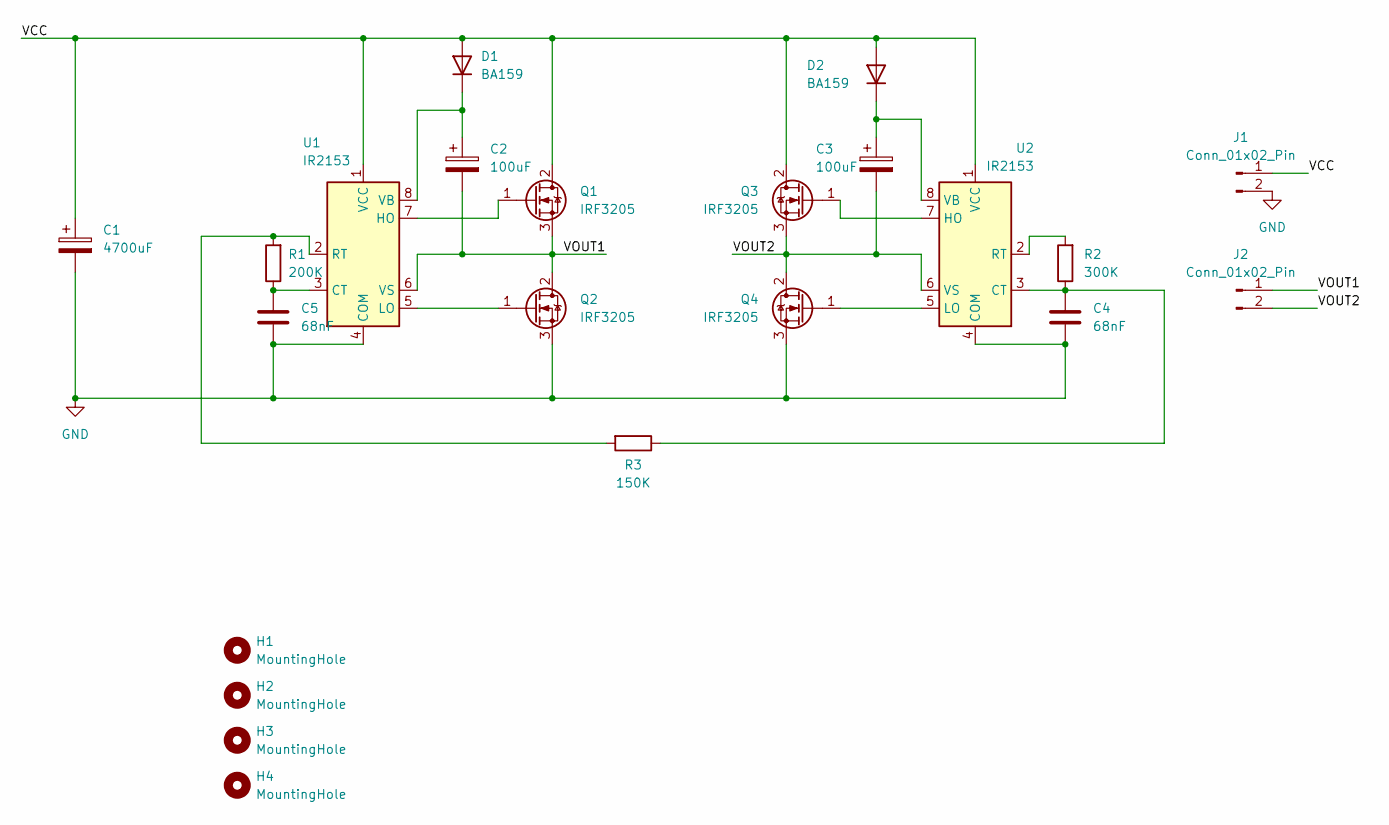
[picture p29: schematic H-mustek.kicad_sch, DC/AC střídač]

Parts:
C1: 4700uF; CP_Radial_D16.0mm_P7.50mm
C2, C3: 100uF; CP_Radial_D8.0mm_P3.50mm
C4, C5: 68nF; C_Axial_L3.8mm_D2.6mm_P7.50mm_Horizontal
D1, D2: BA159; D_DO-41_SOD81_P3.81mm_Vertical_AnodeUp
H1, H2, H3, H4: MountingHole; MountingHole_3.2mm_M3
J1: Conn_01x02_Pin; AMASS_XT30UPB-F_1x02_P5.0mm_Vertical
J2: Conn_01x02_Pin; SolderWire-2.5sqmm_1x02_P7.2mm_D2.4mm_OD3.6mm
Q1, Q2, Q3, Q4: IRF3205; TO-263-3_TabPin2
R1: 200K; R_Axial_DIN0207_L6.3mm_D2.5mm_P7.62mm_Horizontal
R2: 300K; R_Axial_DIN0207_L6.3mm_D2.5mm_P7.62mm_Horizontal
R3: 150K; R_Axial_DIN0207_L6.3mm_D2.5mm_P7.62mm_Horizontal
U1, U2: IR2153; DIP-8_W7.62mm

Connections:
/VCC: C1.1, D1.2 (A), D2.2 (A), J1.1, Q1.2 (D), Q3.2 (D), U1.1 (VCC), U2.1 (VCC)
/VOUT1: C2.2, J2.1, Q1.3 (S), Q2.2 (D), U1.6 (VS)
/VOUT2: C3.2, J2.2, Q3.3 (S), Q4.2 (D), U2.6 (VS)
GND: C1.2, C4.2, C5.2, J1.2, Q2.3 (S), Q4.3 (S), U1.4 (COM), U2.4 (COM)
unnamed: C2.1, D1.1 (K), U1.8 (VB)
unnamed: C3.1, D2.1 (K), U2.8 (VB)
unnamed: Q1.1 (G), U1.7 (HO)
unnamed: Q2.1 (G), U1.5 (LO)
unnamed: Q3.1 (G), U2.7 (HO)
unnamed: Q4.1 (G), U2.5 (LO)
unnamed: C5.1, R1.1, U1.3 (CT)
unnamed: R1.2, R3.2, U1.2 (RT)
unnamed: C4.1, R2.1, R3.1, U2.3 (CT)
unnamed: R2.2, U2.2 (RT)

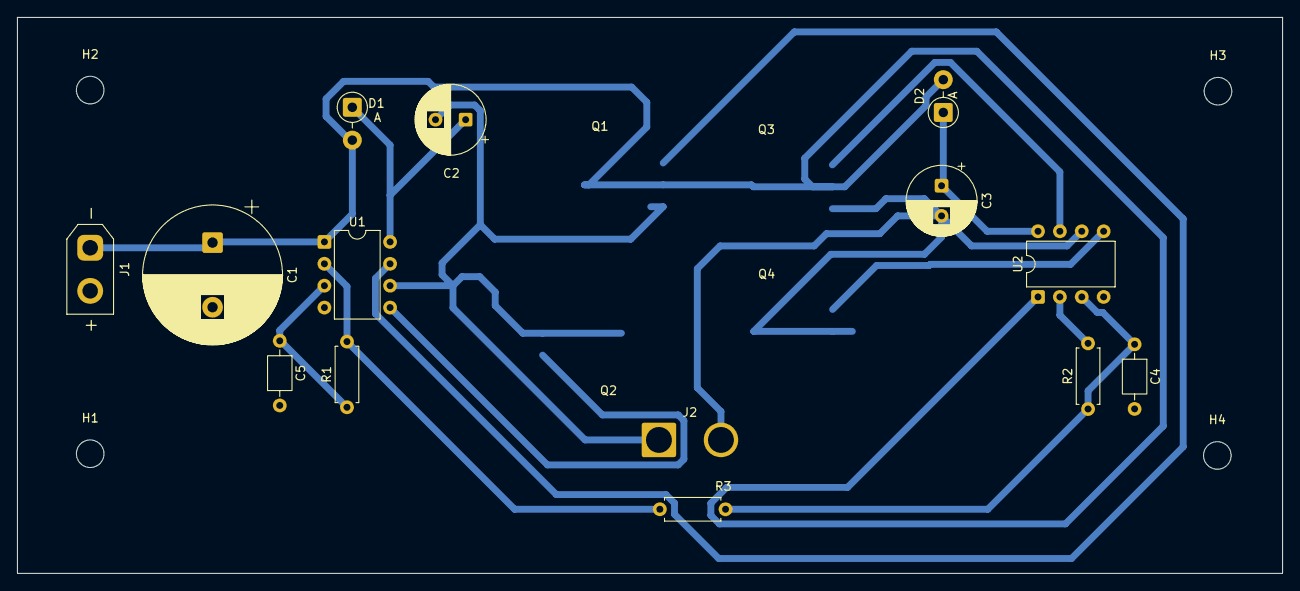
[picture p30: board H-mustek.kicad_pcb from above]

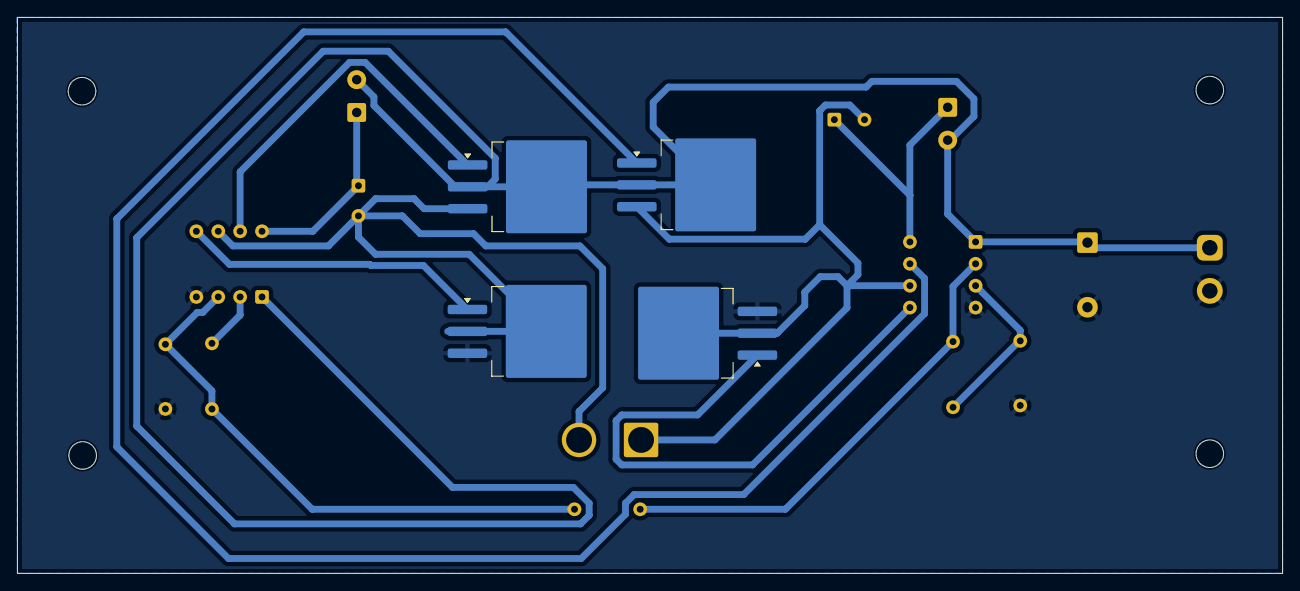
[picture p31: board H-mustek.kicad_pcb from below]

Board: 2 copper layers, 146.8 x 64.5 mm, 22 parts (4 on the bottom side), 14 nets.

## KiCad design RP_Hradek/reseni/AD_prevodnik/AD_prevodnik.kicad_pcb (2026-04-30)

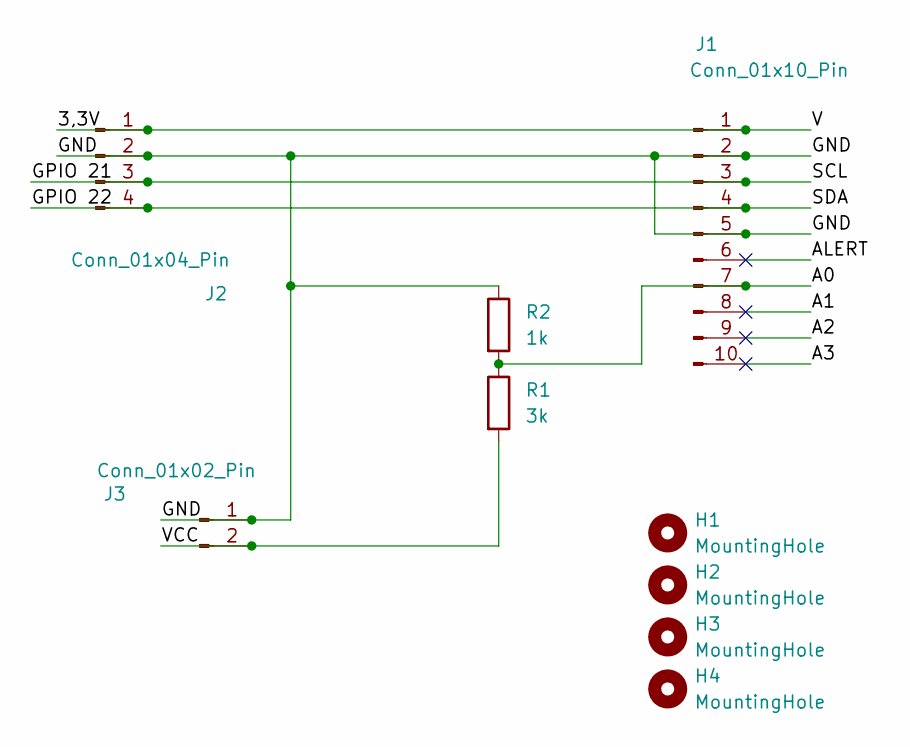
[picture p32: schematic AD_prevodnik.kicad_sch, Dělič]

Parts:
H1, H2, H3, H4: MountingHole; MountingHole_2.2mm_M2
J1: Conn_01x10_Pin; PinHeader_1x10_P2.54mm_Vertical
J2: Conn_01x04_Pin; PinHeader_1x04_P2.54mm_Vertical
J3: Conn_01x02_Pin; AMASS_XT30UPB-F_1x02_P5.0mm_Vertical
R1: 3k; R_Axial_DIN0204_L3.6mm_D1.6mm_P5.08mm_Horizontal
R2: 1k; R_Axial_DIN0204_L3.6mm_D1.6mm_P5.08mm_Horizontal

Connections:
/3,3V: J1.1, J2.1
/A0: J1.7, R1.1, R2.2
/A1: J1.8
/A2: J1.9
/A3: J1.10
/ALERT: J1.6
/GND: J1.2, J1.5, J2.2, J3.1, R2.1
/GPIO 21: J1.3, J2.3
/GPIO 22: J1.4, J2.4
/VCC: J3.2, R1.2

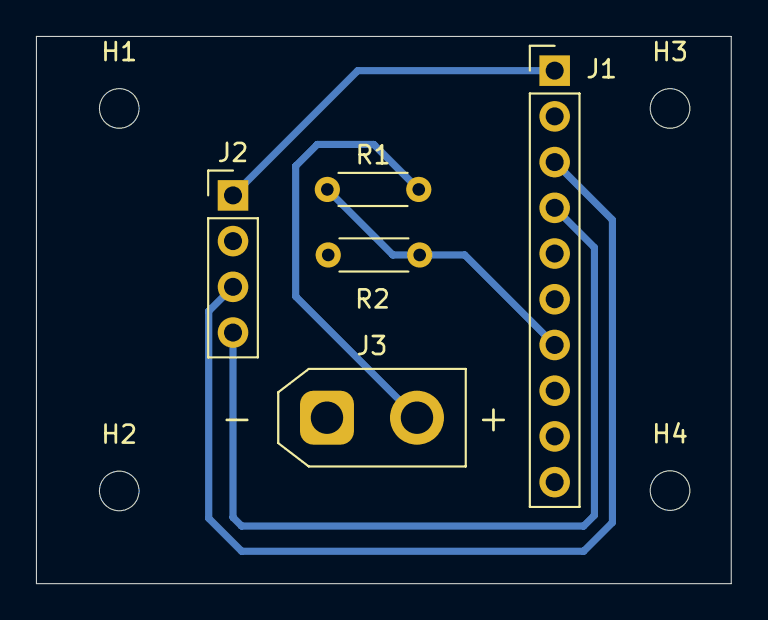
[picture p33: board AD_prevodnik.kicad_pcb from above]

Board: 2 copper layers, 38.6 x 30.4 mm, 9 parts (0 on the bottom side), 6 nets.

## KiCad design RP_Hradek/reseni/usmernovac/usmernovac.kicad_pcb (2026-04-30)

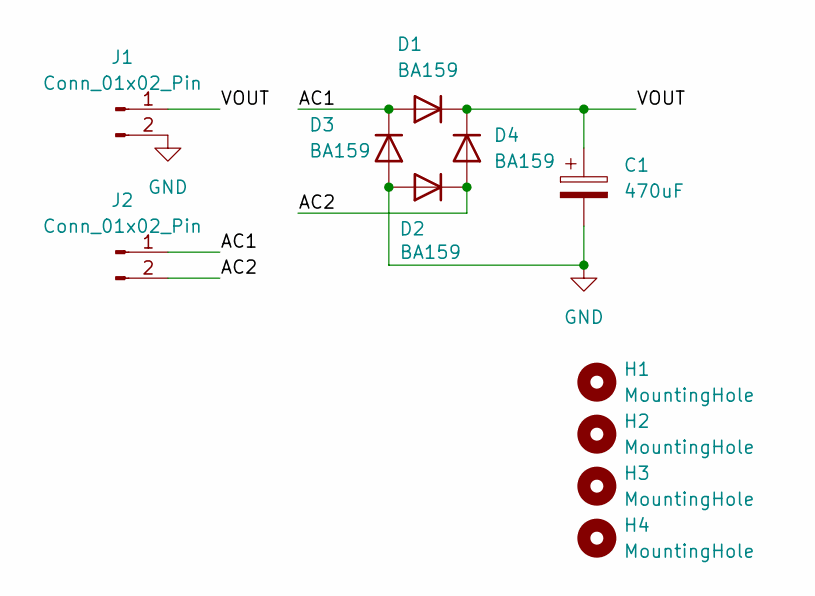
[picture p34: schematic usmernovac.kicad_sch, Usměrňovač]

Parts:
C1: 470uF; CP_Radial_D8.0mm_P5.00mm
D1, D2, D3, D4: BA159; D_DO-41_SOD81_P10.16mm_Horizontal
H1, H2, H3, H4: MountingHole; MountingHole_2.2mm_M2
J1, J2: Conn_01x02_Pin; SolderWire-2sqmm_1x02_P7.8mm_D2mm_OD3.9mm

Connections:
/AC1: D1.2 (A), D3.1 (K), J2.1
/AC2: D2.1 (K), D4.2 (A), J2.2
/VOUT: C1.1, D1.1 (K), D4.1 (K), J1.1
GND: C1.2, D2.2 (A), D3.2 (A), J1.2

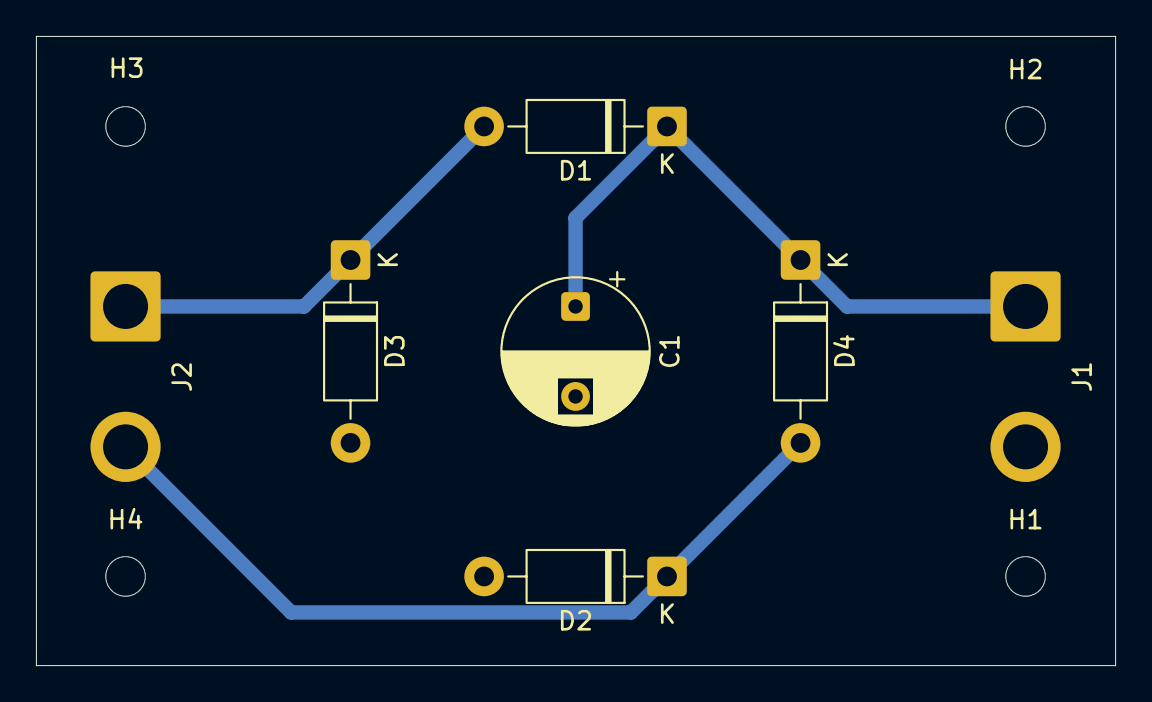
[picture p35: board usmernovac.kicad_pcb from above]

Board: 2 copper layers, 60.0 x 35.0 mm, 11 parts (0 on the bottom side), 4 nets.

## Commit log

2026-02-10 díly
    [RP_dily.xlsx]
2026-03-19 M a U poprve
    [H-mustek.kicad_pcb, H-mustek.kicad_sch, usmernovac.kicad_pcb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]
2026-04-30 repo ready k odevzdani¨
    [AD_prevodnik.kicad_pcb, AD_prevodnik.kicad_sch, H-mustek.kicad_pcb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]
